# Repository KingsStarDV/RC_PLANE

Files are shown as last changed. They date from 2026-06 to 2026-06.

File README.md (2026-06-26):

# RC_PLANE

TRANSMITTER WIRING DIAGRAM--



RECEIVER WIRING DIAGRAM--



SO, As you would already have seen that the project is about a DIY RC PLANE...

**What is the RC plane?**
It is just a simple RC PLANE that i built..
It is neither inspired from any real life plane nor copied from any existing model on the internet..

**Why did you build it?**
Mainly bacause of fun but also, i saw there were little to no cheap RC PLANE BUILDS..
This build is possible with off the shelf parts and no 3D Printing..

**Parts needed**
| S.No | Component | Quantity | Unit Price (INR) | Total Price (INR) | Source | URL |
|---|---|---|---|---|---|---|
| 1 | ESP32 NodeMCU-32 WiFi Bluetooth Development Board (30-pin) | 2 | 385 | 770 | Robocraze | https://robocraze.com/products/nodemcu-32-wifi-bluetooth-esp32-development-board30-pin |
| 2 | NRF24L01 2.4GHz PA LNA SMA Transceiver Wireless Module | 2 | 140 | 280 | Electropi | https://www.electropi.in/nrf24l01-2.4ghz-pa-lna-sma-transceiver-wireless-module-india |
| 3 | KY023 2-Axis XY Analog Joystick Module | 2 | 25 | 50 | Robosap | https://robosap.in/product/2-axis-xy-analog-joystick-module/ |
| 4 | 100uF Capacitor | 2 | 10 | 20 | Local Market | — |
| 5 | 100nF Capacitor | 2 | 10 | 29 | Local Market | — |
| 6 | Push Button | 2 | 15 | 30 | Local Market | — |
| 7 | LM2596 DC-DC Step-Down Converter Module | 2 | 50 | 100 | MakerBazar | https://makerbazar.in/products/lm2596-dc-dc-converter-step-down-module |
| 8 | Samsung SDI INR18650 Li-Ion Rechargeable Cell | 2 | 250 | 500 | MakerBazar | https://makerbazar.in/products/samsung-sdi-inr18650-li-ion-rechargeable-cells |
| 9 | 2S BMS + Charger Circuit (18650 Lithium Battery Protection Board) | 1 | 100 | 100 | MakerBazar | https://makerbazar.in/products/18650-bms-lithium-battery-protection-board |
| 10 | AMS1117 3.3v | 1 | 15 | 15 | Local Market | -- |
| 11 | BLDC Motor + ESC (30A) [Combo Pack] | 1 | 840 | 840 | Flyrobo | https://www.flyrobo.in/combo-kit-1000kv-brushless-motor-plus-30a-esc-plus-1045-propeller-pair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 |
| 12 | Li-Po 3S Battery | 1 | 1320 | 1320 | Quartz Components | https://quartzcomponents.com/products/absd-11-1v-2200mah-3s-80c-lithium-polymer-rechargeable-battery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 |
| 13 | SG90 Servo Motor | 3 | 125 | 375 | Flyrobo | https://www.flyrobo.in/sg90-9g-micro-pro-servo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 |
| 14 | Miscellaneous Items (tape/metal wire/wooden sticks/color etc) | 1 | 450 | 450 | Local Market | — |
| 15 | LiPo Charger | 1 | 340 | 340 | FlyRobo | https://www.flyrobo.in/imax-b3-lipo-balance-charger-for-2-3-cell-lipo-battery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 |
| 16 | Hard Cardboard Ply | 2 | 100 | 200 | Local Market | --- |
| 17 | Hardened Thermocol Sheet | 2 | 50 | 100 | Local Market | --- |

**Step by step assembly instructions**

*These intructions can vary for your model.*
*You may refer to the youtube video by JakeMakes-* https://youtu.be/zVdXEjUrwiI?si=U4ZD6KPrB3ZJLI3x

Fuselage-
1) make a cuboid of (Length x Breadth x Height) of 65cm x 8cm x 7cm.
2)On one side of the cuboid (along the length), make the nose of the airplane..
3)Add a tail to the airplane of roughly 10m height.

Wings-
1)Make a 60cm x 13 cm rectangle shape out of thermocol.
2)From each side of the longer edge cut a rectangle out at a distance of 35cm..
     [Or if you didnt understood, here is a image]
     

3) Reattach the cut part with help of some strong tape..Remember the flap must b eable to move both up and down.

Tail Wings-
1) Similar to the wings make a rectangle of 20cm x 7cm and cut out a part for the flap..
2) similar to the wings reaatach the flap with tape leaving room for movement..

Assembly-
1)Attach the wing to the fuselage at about 17cm of distance from the extreme point of nose.
2)Secure it with rubber bands.
3)Attach the tail wings with either glue (NOT SUPER GLUE AS IT WOULD BURN THE THERMOCOL) or you can use Hot Glue..

4)Attach the Servo Motors of the wing and tail wings and make a hinge syste so that they can allow the flaps to move.
5)Attach the BLDC motor with rubber bands and place the ESC, Receiver and Batery according to the wieght distrubution, so that the plane is balanced at around the middle of wings.

6)And you are all set.

**Configure the Receiver and Transmitter**
Open the TRASMITTER code provided and set a address of your choice in the code. Remeber this address exactly.

In the reciver code, enter the same exact code.
Both the transmitter and receiver by default code are set to maximum power delivery and balanced between low latency and bandwidth.

.............................................................................................................................






## How to Upload the Code

**Requirements:**
- Arduino IDE installed
- ESP32 board package installed
- RF24 library installed

**Steps:**
1. Open Arduino IDE
2. Go to File → Open → select `transmitter.ino` (or `receiver.ino`)
3. Go to Tools → Board → select `ESP32 Dev Module`
4. Go to Tools → Port → select your COM port
5. Click the Upload button (→)
6. Repeat for the second ESP32 with the receiver code

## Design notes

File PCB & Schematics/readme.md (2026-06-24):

In this folder you will find PCB and Schematic of the project..

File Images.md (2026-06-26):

TRANSMITTER -





......................................................................................................................................................................................................................

RECEIVER -





.............................................................................................................................................................................................................................................

Aircraft -










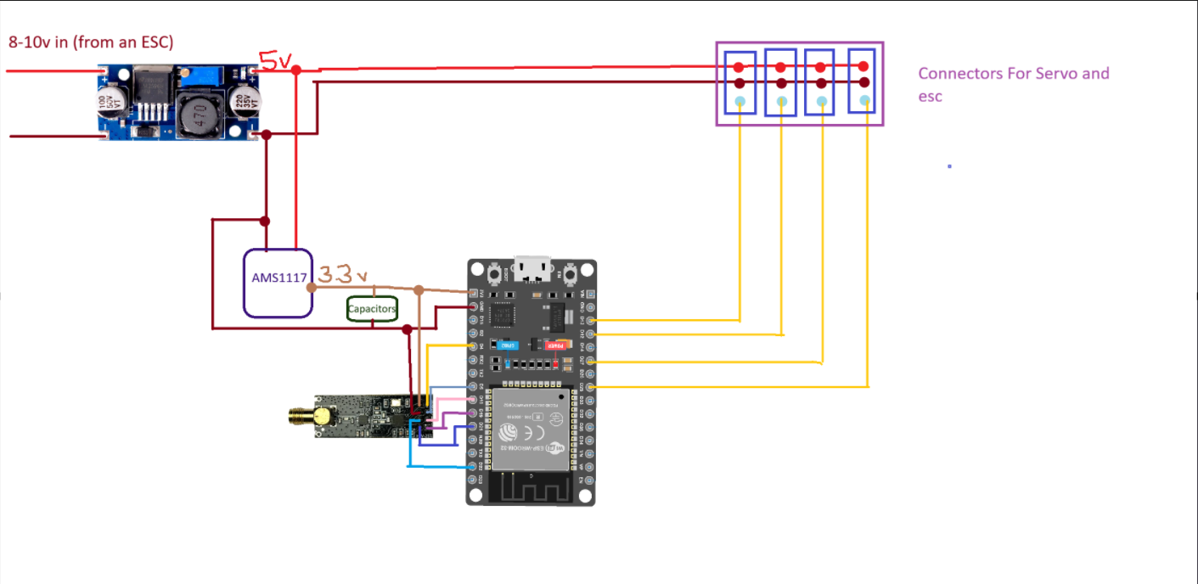
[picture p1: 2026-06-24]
PCB & Schematics/Screenshot 2026-06-24 211623.png

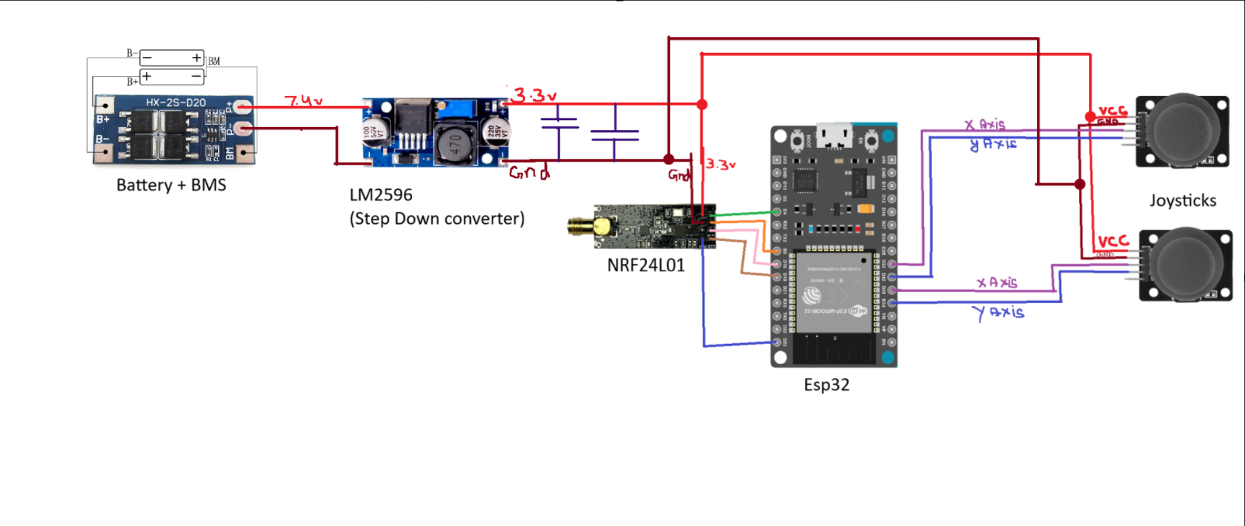
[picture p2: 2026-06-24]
PCB & Schematics/Screenshot 2026-06-24 205755.png

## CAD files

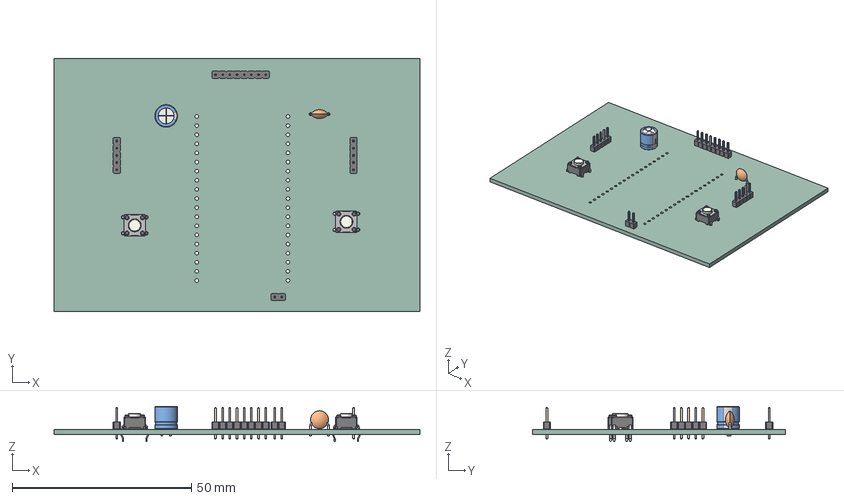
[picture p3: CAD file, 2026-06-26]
3D Model/F3Z & Step/STEP files/transmitter.step
102.0 x 70.5 x 9.80 mm
SW_TH_Tactile_Omron_B3F-100x x 2
C_Disc_D50mm_W25mm_P500mm
PinHeader_1x05_P200mm_Vertical x 2
CP_Radial_D63mm_P250mm
PinHeader_1x08_P200mm_Vertical
PinHeader_1x02_P200mm_Vertical
rcpne_PCB

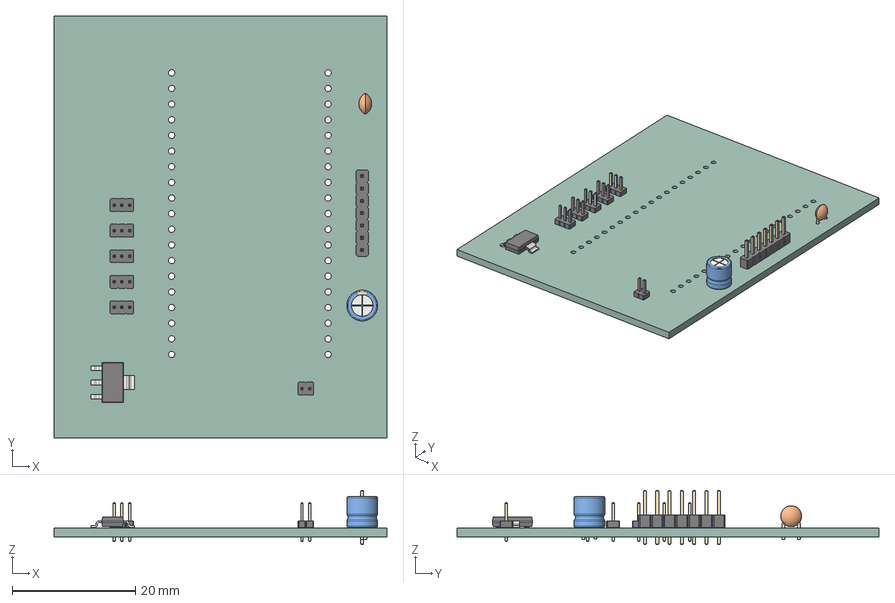
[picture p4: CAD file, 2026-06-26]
3D Model/PCB/reciever.step
54.0 x 68.5 x 8.80 mm
PinHeader_1x07_P200mm_Vertical
PinHeader_1x03_P127mm_Vertical x 5
PinHeader_1x02_P127mm_Vertical
SOT-223
C_Disc_D34mm_W21mm_P250mm
CP_Radial_D50mm_P200mm
reciver_PCB

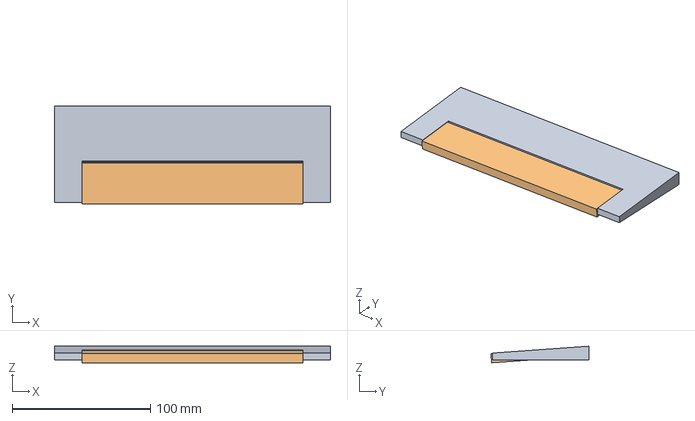
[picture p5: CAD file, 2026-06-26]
3D Model/F3Z & Step/STEP files/Tail Wing.step
200.0 x 71.2 x 12.1 mm

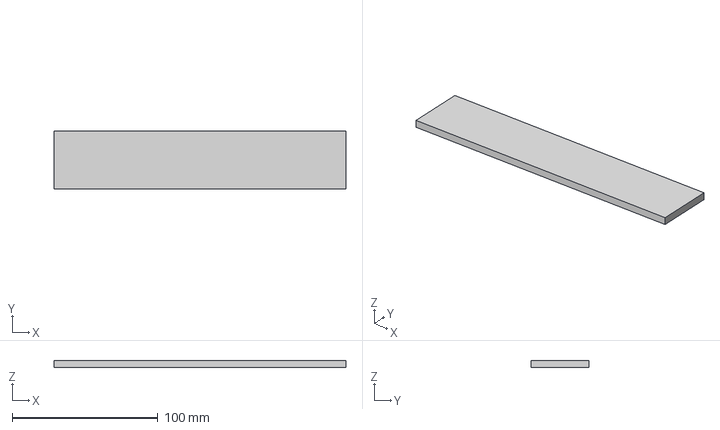
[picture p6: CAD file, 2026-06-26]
3D Model/F3Z & Step/STEP files/Ailerons.step
200.0 x 40.0 x 5.00 mm

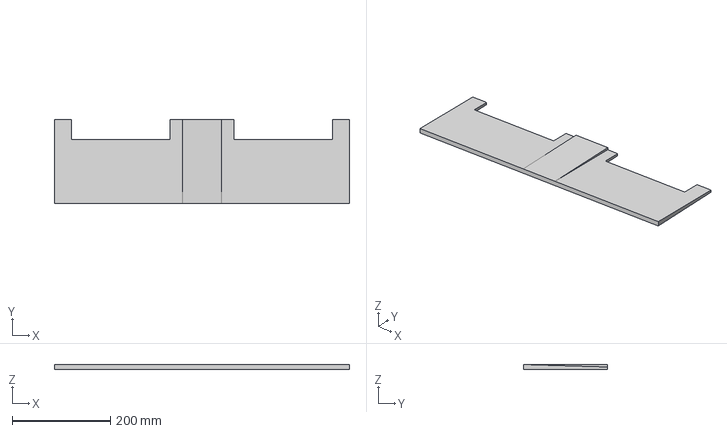
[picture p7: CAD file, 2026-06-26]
3D Model/F3Z & Step/STEP files/Wing.step
600.0 x 170.0 x 10.0 mm

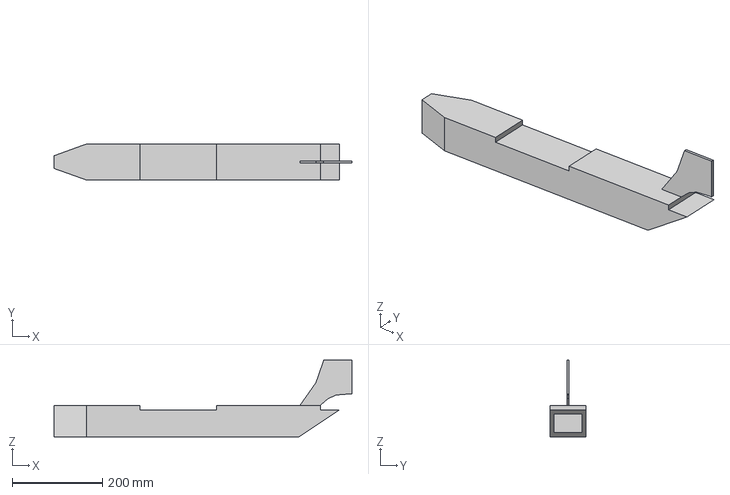
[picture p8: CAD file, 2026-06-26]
3D Model/F3Z & Step/STEP files/Fuselage.step
660.0 x 80.0 x 170.0 mm

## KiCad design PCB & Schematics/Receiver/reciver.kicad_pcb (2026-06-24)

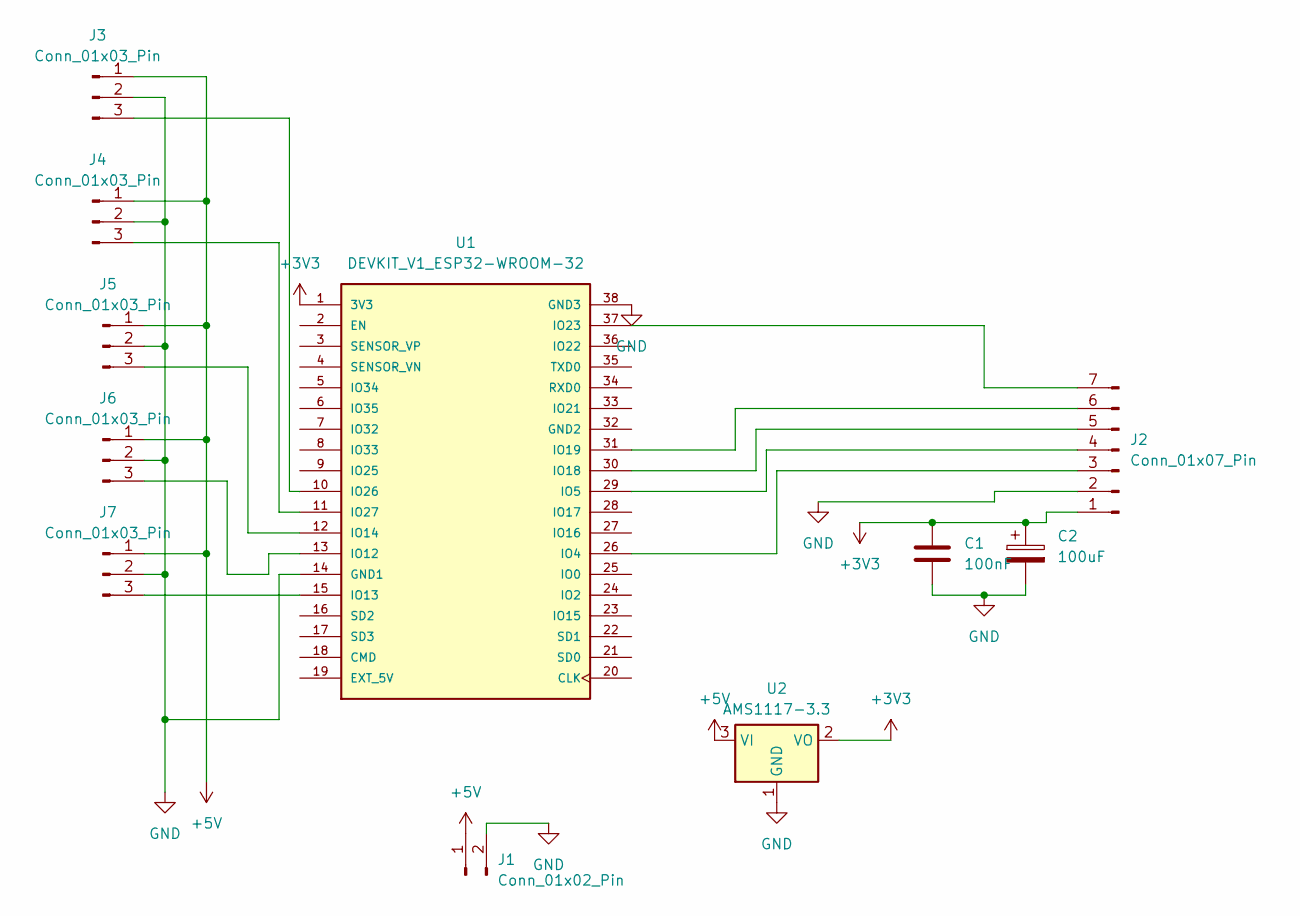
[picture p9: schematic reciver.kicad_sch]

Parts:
C1: 100nF; C_Disc_D3.4mm_W2.1mm_P2.50mm
C2: 100uF; CP_Radial_D5.0mm_P2.00mm
J1: Conn_01x02_Pin; PinHeader_1x02_P1.27mm_Vertical
J2: Conn_01x07_Pin; PinHeader_1x07_P2.00mm_Vertical
J3, J4, J5, J6, J7: Conn_01x03_Pin; PinHeader_1x03_P1.27mm_Vertical
U1: DEVKIT_V1_ESP32-WROOM-32; MODULE_DEVKIT_V1_ESP32-WROOM-32; PARTREV N/A
U2: AMS1117-3.3; SOT-223-3_TabPin2

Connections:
+3V3: C1.1, C2.1, J2.1, U1.1 (3V3), U2.2 (VO)
+5V: J1.1, J3.1, J4.1, J5.1, J6.1, J7.1, U2.3 (VI)
GND: C1.2, C2.2, J1.2, J2.2, J3.2, J4.2, J5.2, J6.2, J7.2, U1.14 (GND1), U1.38 (GND3), U2.1 (GND)
unnamed: J2.3, U1.26 (IO4)
unnamed: J2.4, U1.29 (IO5)
unnamed: J2.5, U1.30 (IO18)
unnamed: J2.6, U1.31 (IO19)
unnamed: J2.7, U1.37 (IO23)
unnamed: J3.3, U1.10 (IO26)
unnamed: J4.3, U1.11 (IO27)
unnamed: J5.3, U1.12 (IO14)
unnamed: J6.3, U1.13 (IO12)
unnamed: J7.3, U1.15 (IO13)

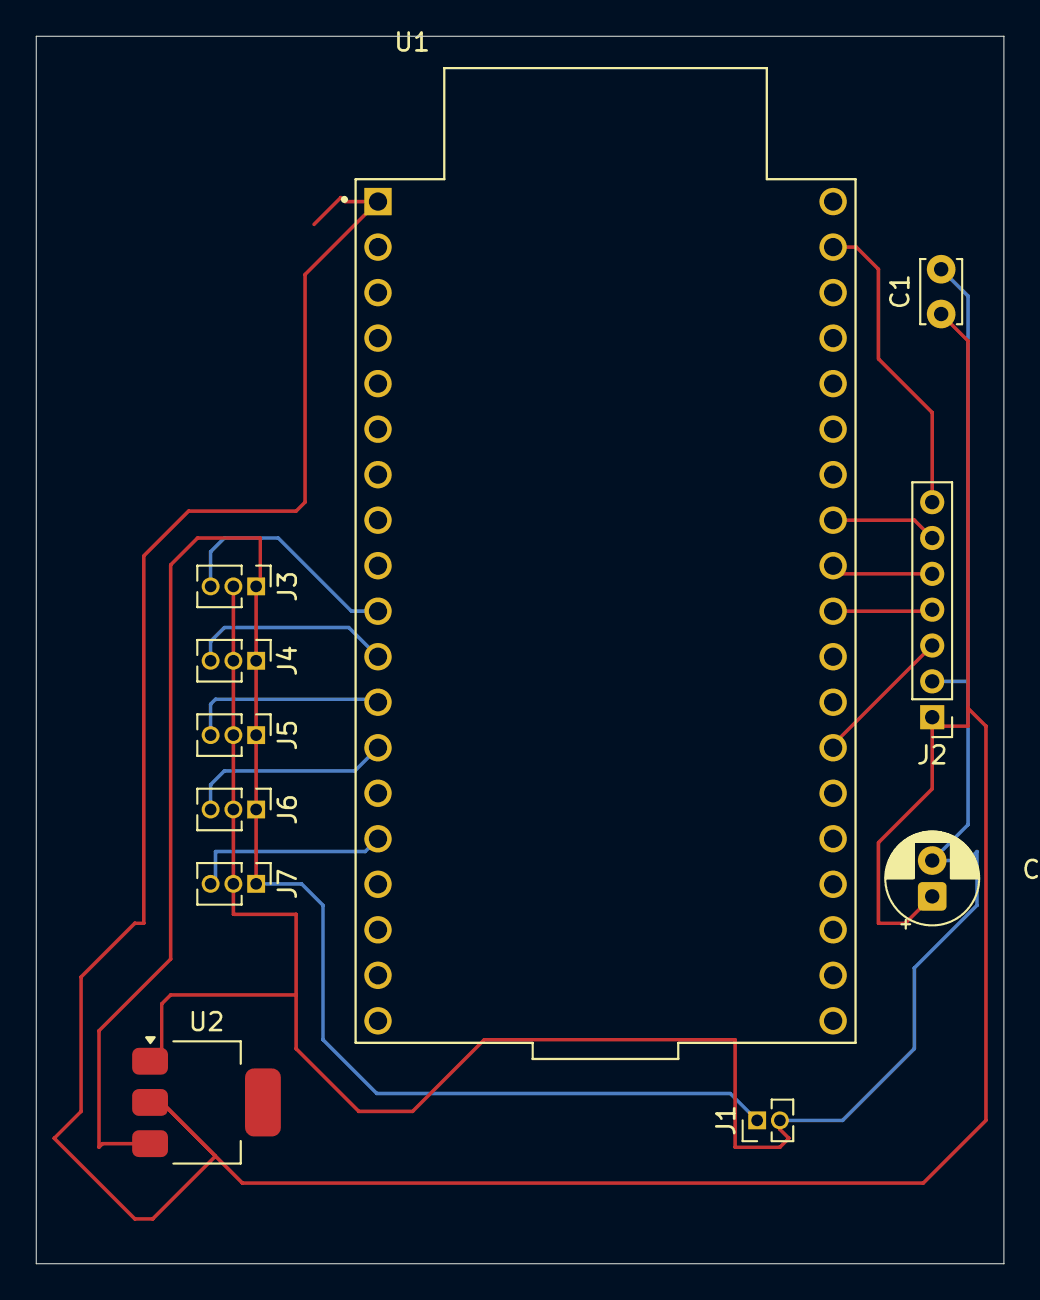
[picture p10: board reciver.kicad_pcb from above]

Board: 2 copper layers, 54.0 x 68.5 mm, 11 parts (0 on the bottom side), 13 nets.

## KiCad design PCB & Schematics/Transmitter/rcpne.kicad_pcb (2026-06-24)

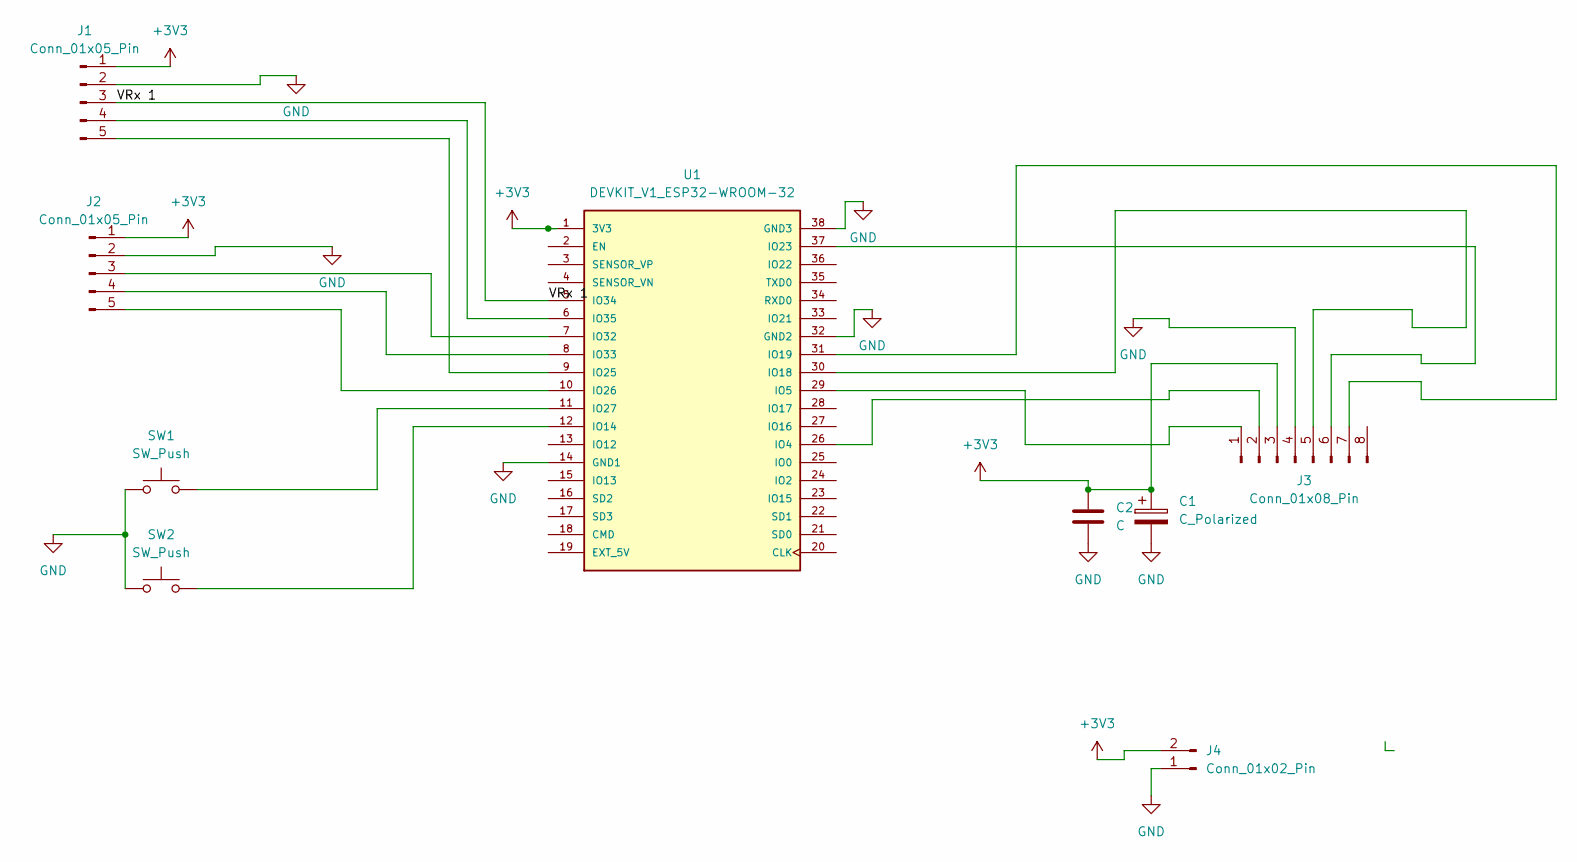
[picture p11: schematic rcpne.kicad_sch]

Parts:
C1: C_Polarized; CP_Radial_D6.3mm_P2.50mm
C2: C; C_Disc_D5.0mm_W2.5mm_P5.00mm
J1, J2: Conn_01x05_Pin; PinHeader_1x05_P2.00mm_Vertical
J3: Conn_01x08_Pin; PinHeader_1x08_P2.00mm_Vertical
J4: Conn_01x02_Pin; PinHeader_1x02_P2.00mm_Vertical
SW1, SW2: SW_Push; SW_TH_Tactile_Omron_B3F-100x
U1: DEVKIT_V1_ESP32-WROOM-32; MODULE_DEVKIT_V1_ESP32-WROOM-32; PARTREV N/A

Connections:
+3V3: C1.1, C2.1, J1.1, J2.1, J3.3, J4.2, U1.1 (3V3)
/VRx 1: J1.3, U1.5 (IO34)
GND: C1.2, C2.2, J1.2, J2.2, J3.4, J4.1, SW1.1, SW2.1, U1.14 (GND1), U1.32 (GND2), U1.38 (GND3)
unnamed: J1.4, U1.6 (IO35)
unnamed: J1.5, U1.9 (IO25)
unnamed: J2.3, U1.7 (IO32)
unnamed: J2.4, U1.8 (IO33)
unnamed: J2.5, U1.10 (IO26)
unnamed: J3.1, U1.29 (IO5)
unnamed: J3.2, U1.26 (IO4)
unnamed: J3.5, U1.30 (IO18)
unnamed: J3.6, U1.37 (IO23)
unnamed: J3.7, U1.31 (IO19)
unnamed: SW2.2, U1.12 (IO14)
unnamed: SW1.2, U1.11 (IO27)

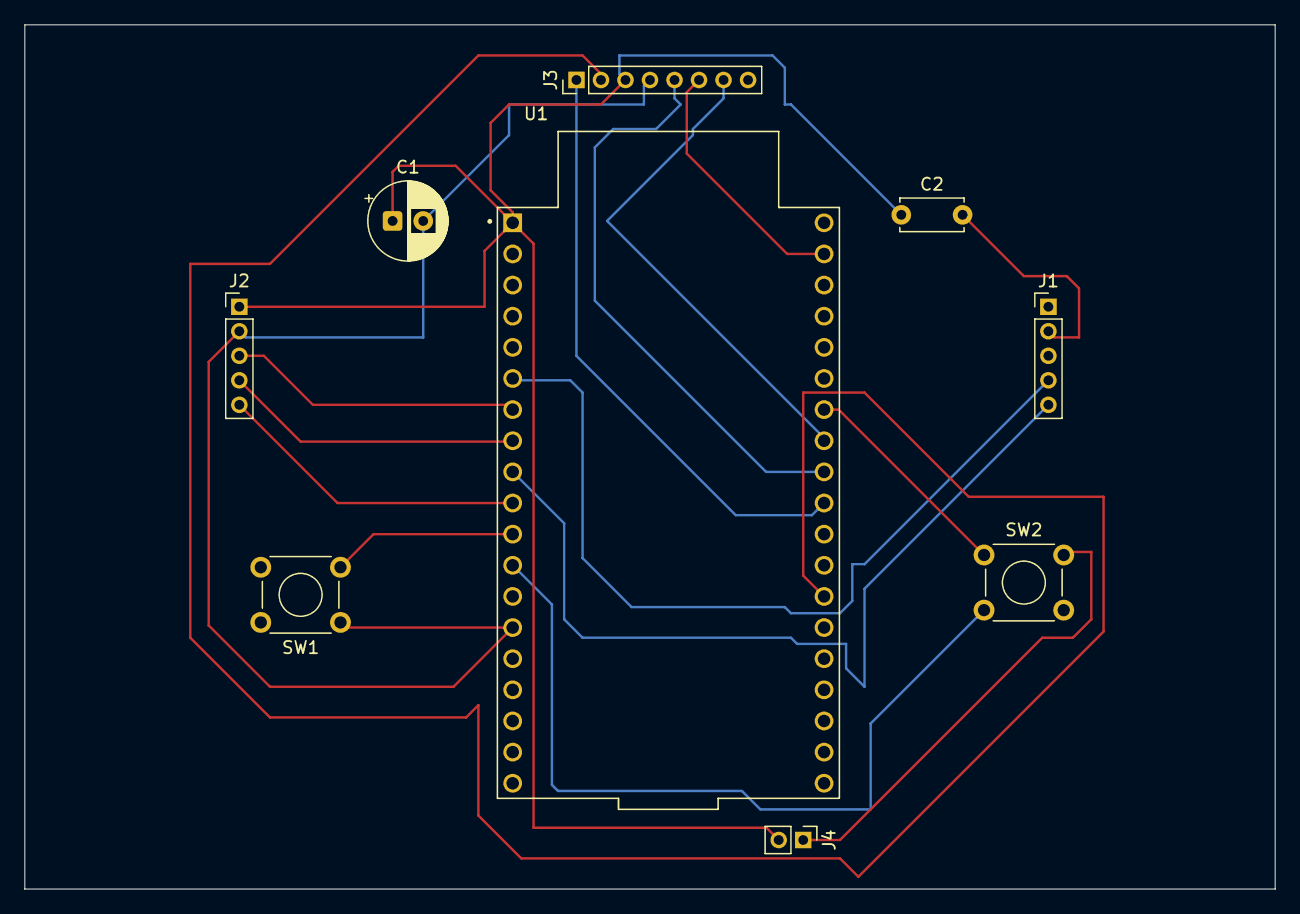
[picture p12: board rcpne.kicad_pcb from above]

Board: 2 copper layers, 102.0 x 70.5 mm, 9 parts (0 on the bottom side), 15 nets.

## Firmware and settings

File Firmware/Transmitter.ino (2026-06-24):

#include <SPI.h>
#include <RF24.h>

int Channel = 108;
const byte address[6] = "complex";

RF24 nrf(4, 5);

struct RCDATA {
  int CH1;
  int CH2;
  int CH3;
  int CH4;
  int CH5;
  int CH6;
};

void setup(){
  Serial.begin(115200);
  pinMode(27, INPUT_PULLUP);
  pinMode(14, INPUT_PULLUP);

  nrf.begin();
  nrf.setPALevel(RF24_PA_MAX);
  nrf.setDataRate(RF24_250KBPS);
  nrf.setChannel(Channel);
  nrf.openWritingPipe(address);
  nrf.stopListening();
}

void loop(){
  RCDATA data;

  data.CH1 = analogRead(34);
  data.CH2 = analogRead(35);
  data.CH3 = analogRead(32);
  data.CH4 = analogRead(33);
  data.CH5 = digitalRead(27);
  data.CH6 = digitalRead(14);

  bool sent = nrf.write(&data, sizeof(data));

  Serial.print("Joystick 1:   ");
  Serial.print("X :");
  Serial.print(data.CH1);
  Serial.print("Y :");
  Serial.println(data.CH2);

  Serial.print("Joystick 2:   ");
  Serial.print("X :");
  Serial.print(data.CH3);
  Serial.print("Y :");
  Serial.println(data.CH4);

  Serial.print("Button:   ");
  Serial.print("BTN1 :");
  Serial.print(data.CH5);
  Serial.print("BTN2 :");
  Serial.println(data.CH6);

  Serial.print("Sent Status:");
  Serial.println(sent);

  delay(20);
}

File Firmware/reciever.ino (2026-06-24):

#include <ESP32Servo.h>
#include <SPI.h>
#include <RF24.h>
int Channel = 108;
const byte address[6] = "complex";

RF24 nrf(4, 5);

Servo s1;
Servo s2;
Servo s3;
Servo s4;
Servo s5;


struct RCDATA {
  int CH1;
  int CH2;
  int CH3;
  int CH4;
  int CH5;
  int CH6;
};

void setup() {
  Serial.begin(115200);
  nrf.begin();
  nrf.setPALevel(RF24_PA_MAX);
  nrf.setDataRate(RF24_250KBPS);
  nrf.setChannel(Channel);
  nrf.openReadingPipe(1, address);
  nrf.startListening();
  
  s1.attach(12);
  s2.attach(13);
  s3.attach(14);
  s4.attach(27);
  s5.attach(25);
  

}

void loop(){
  
  if (nrf.available()){
    RCDATA data;
    nrf.read(&data, sizeof(data));


    //For the Servo 1
    
    int mappedX1 = map(data.CH1, 0, 4095, 1000, 1500);
    s1.writeMicroseconds(mappedX1);  

    
    // For the Esc
    
    int mappedY1 = map(data.CH2, 0, 4095, 1000, 2000);
    s2.writeMicroseconds(mappedY1);


    //For the Servo2
    
    int mappedX2 = map(data.CH3, 0, 4095, 1000, 1500);
    s3.writeMicroseconds(mappedX2);

    //For Servo3
    
    int mappedY2 = map(data.CH4, 0, 4095, 1000, 1500);
    s4.writeMicroseconds(mappedY2);




  }        
}
